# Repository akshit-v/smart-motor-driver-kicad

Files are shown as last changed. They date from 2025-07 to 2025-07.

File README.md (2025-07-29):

# Smart-Motor-Driver-kicad
A high-efficiency 60V/40A smart motor driver with real-time current and voltage sensing, reverse polarity protection, and a cost-optimized PCB design
Smart Motor Driver – Kicad

This repository contains the complete design and documentation for a smart motor driver capable of driving two high-current DC motors (up to 60V, 40A each) with real-time voltage and current sensing. The driver is built using discrete components, and gate drivers for H-bridge MOSFET control. It is designed for high-efficiency operation, integrated protection, and microcontroller-based control.

The project includes the full schematic, PCB layout, firmware interface, and performance analysis. It is intended for embedded system applications such as robotics, automation, and motorized systems requiring efficient and protected motor drive control.

---
# Project Features
- **Dual Channel Motor Drive**: Two independent H-Bridge circuits with dedicated gate drivers.
- **High Voltage and Current Support**: Operates at up to 60V input and handles continuous motor current up to 40A per channel.
- **High Efficiency**: Optimized gate drive timing, low-loss power MOSFETs, and minimized switching losses provide efficiency above 90% under load.
- **Current and Voltage Feedback**: Op-amp-based analog sensing circuits for real-time current and voltage monitoring with ±1% accuracy.
- **Reverse Polarity Protection**: Input protection circuit safeguards the board from accidental reverse connections.
- **Microcontroller Interface**: PWM-compatible logic-level inputs for speed and direction control 
- **Integrated Voltage Regulation**: Onboard buck regulators generate 5V and 3.3V rails for logic and sensors.
- **USB-to-Serial Interface**: Using a USB-to-Serial converter (CH340-C) for real-time data logging, motor control, and firmware debugging via serial terminal.
- **Modular Design**: Separated sections for control logic, power stages, sensing, and regulation.

---

## Schematic Highlights

- **Power Section**: Includes reverse polarity protection, input filtering, and buck converters (AP63205WU, AP7316-C) for 5V and 3.3V rails.
- **Gate Drivers**: MC33883 used to drive the high- and low-side N-channel MOSFETs for each H-bridge.
- **Motor Channels**: Two H-Bridge configurations, each with four MOSFETs and flyback diodes for inductive protection.
- **Current Sensing**: Differential amplifier circuits with op-amps (LM358) for low-side current sensing on each motor.
- **Voltage Monitoring**: Voltage divider and op-amp buffer stages for voltage feedback to the controller.
- **Microcontroller Interface**: PWM signal lines, direction pins, and feedback outputs prepared for logic-level interfacing.

---

## Tools and Components Used

- **Schematic & PCB Design**: KiCad
- **Analog Simulation**: Proteus
- **Gate Driver**: MC33883
- **Microcontroller Target**: ESP32
- **Op-Amps**: LM358 (for current and voltage sensing)
- **MOSFETs**: N-channel high-current rated, low Rds(on)
- **Voltage Regulators**: AP63205WU, AP7316-C for 5V and 3.3V and 74HCT244 for level shifting
- **Other Tools**: Proteus (for logic testing), T-Cad (device simulation reference)

---

## Applications

- Custom embedded robotic platforms
- Industrial or academic motor control systems

---

## Performance Summary

- **Efficiency**: >90% at full load
- **Current Measurement Error**: ±1% (tested using calibrated load)
- **MOSFET Temperature Rise**: Within safe limits under continuous 30A drive with proper heat dissipation
- **Cost**: 40% lower than comparable commercial motor drivers with similar specs

---
[View Schematic (PDF)](Schematic.pdf)
---
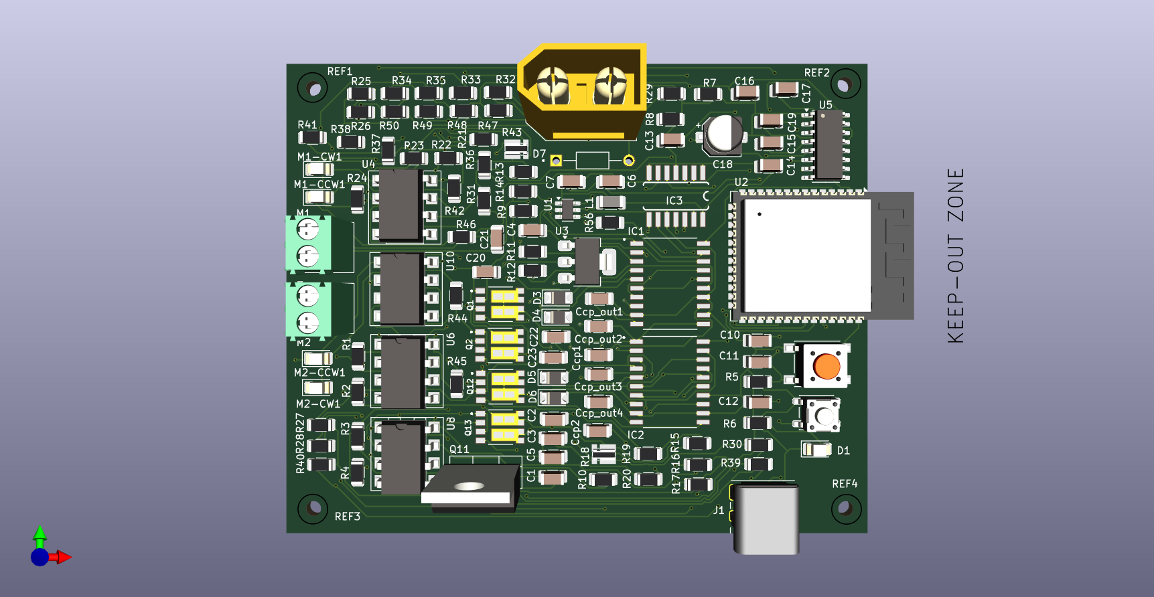
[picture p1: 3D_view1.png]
3D PCB View 1

---
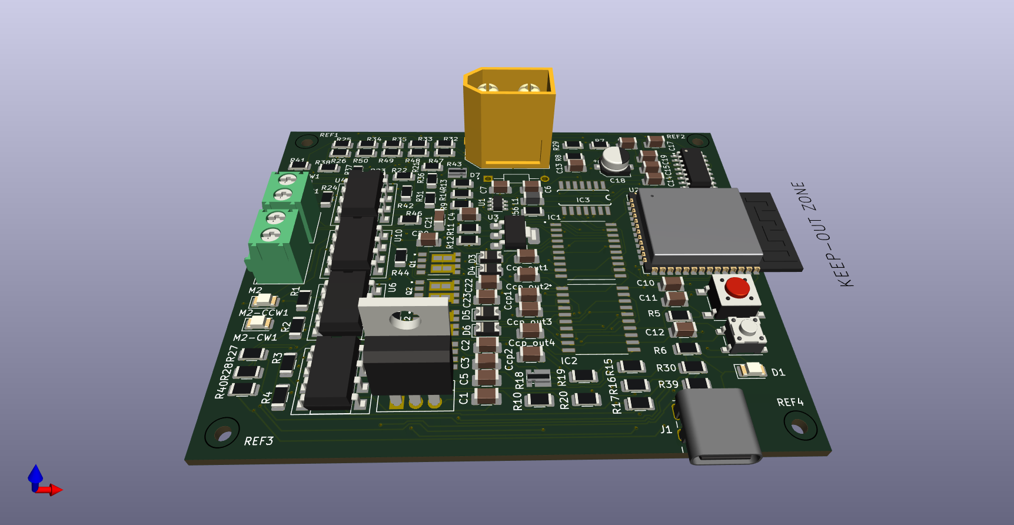
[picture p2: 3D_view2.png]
3D PCB View 2

---
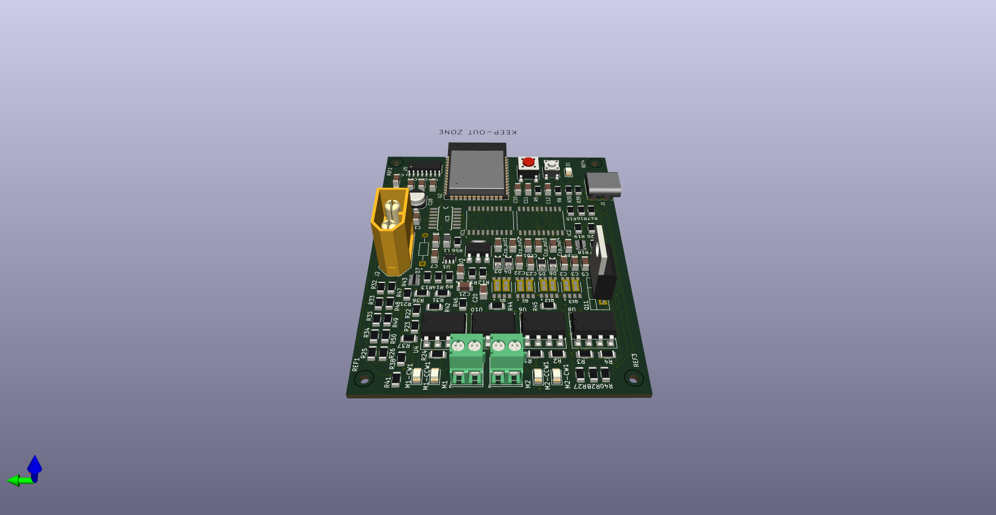
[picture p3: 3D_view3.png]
3D PCB View 3

---
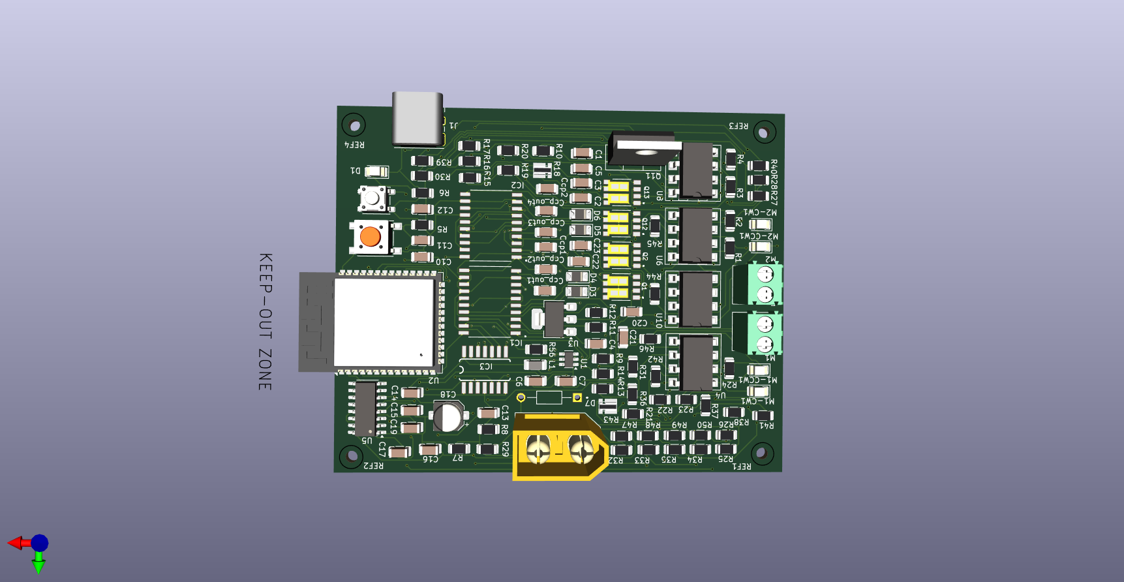
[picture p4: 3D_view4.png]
3D PCB View 4

---
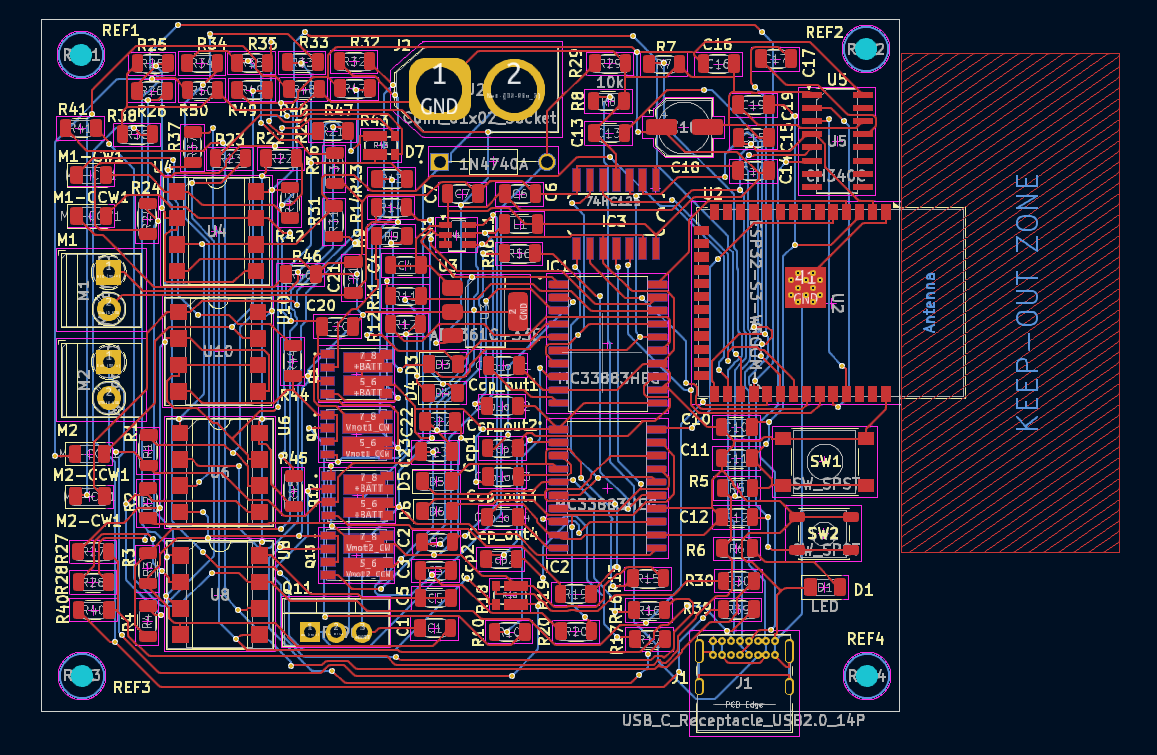
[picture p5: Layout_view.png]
Layout View

---

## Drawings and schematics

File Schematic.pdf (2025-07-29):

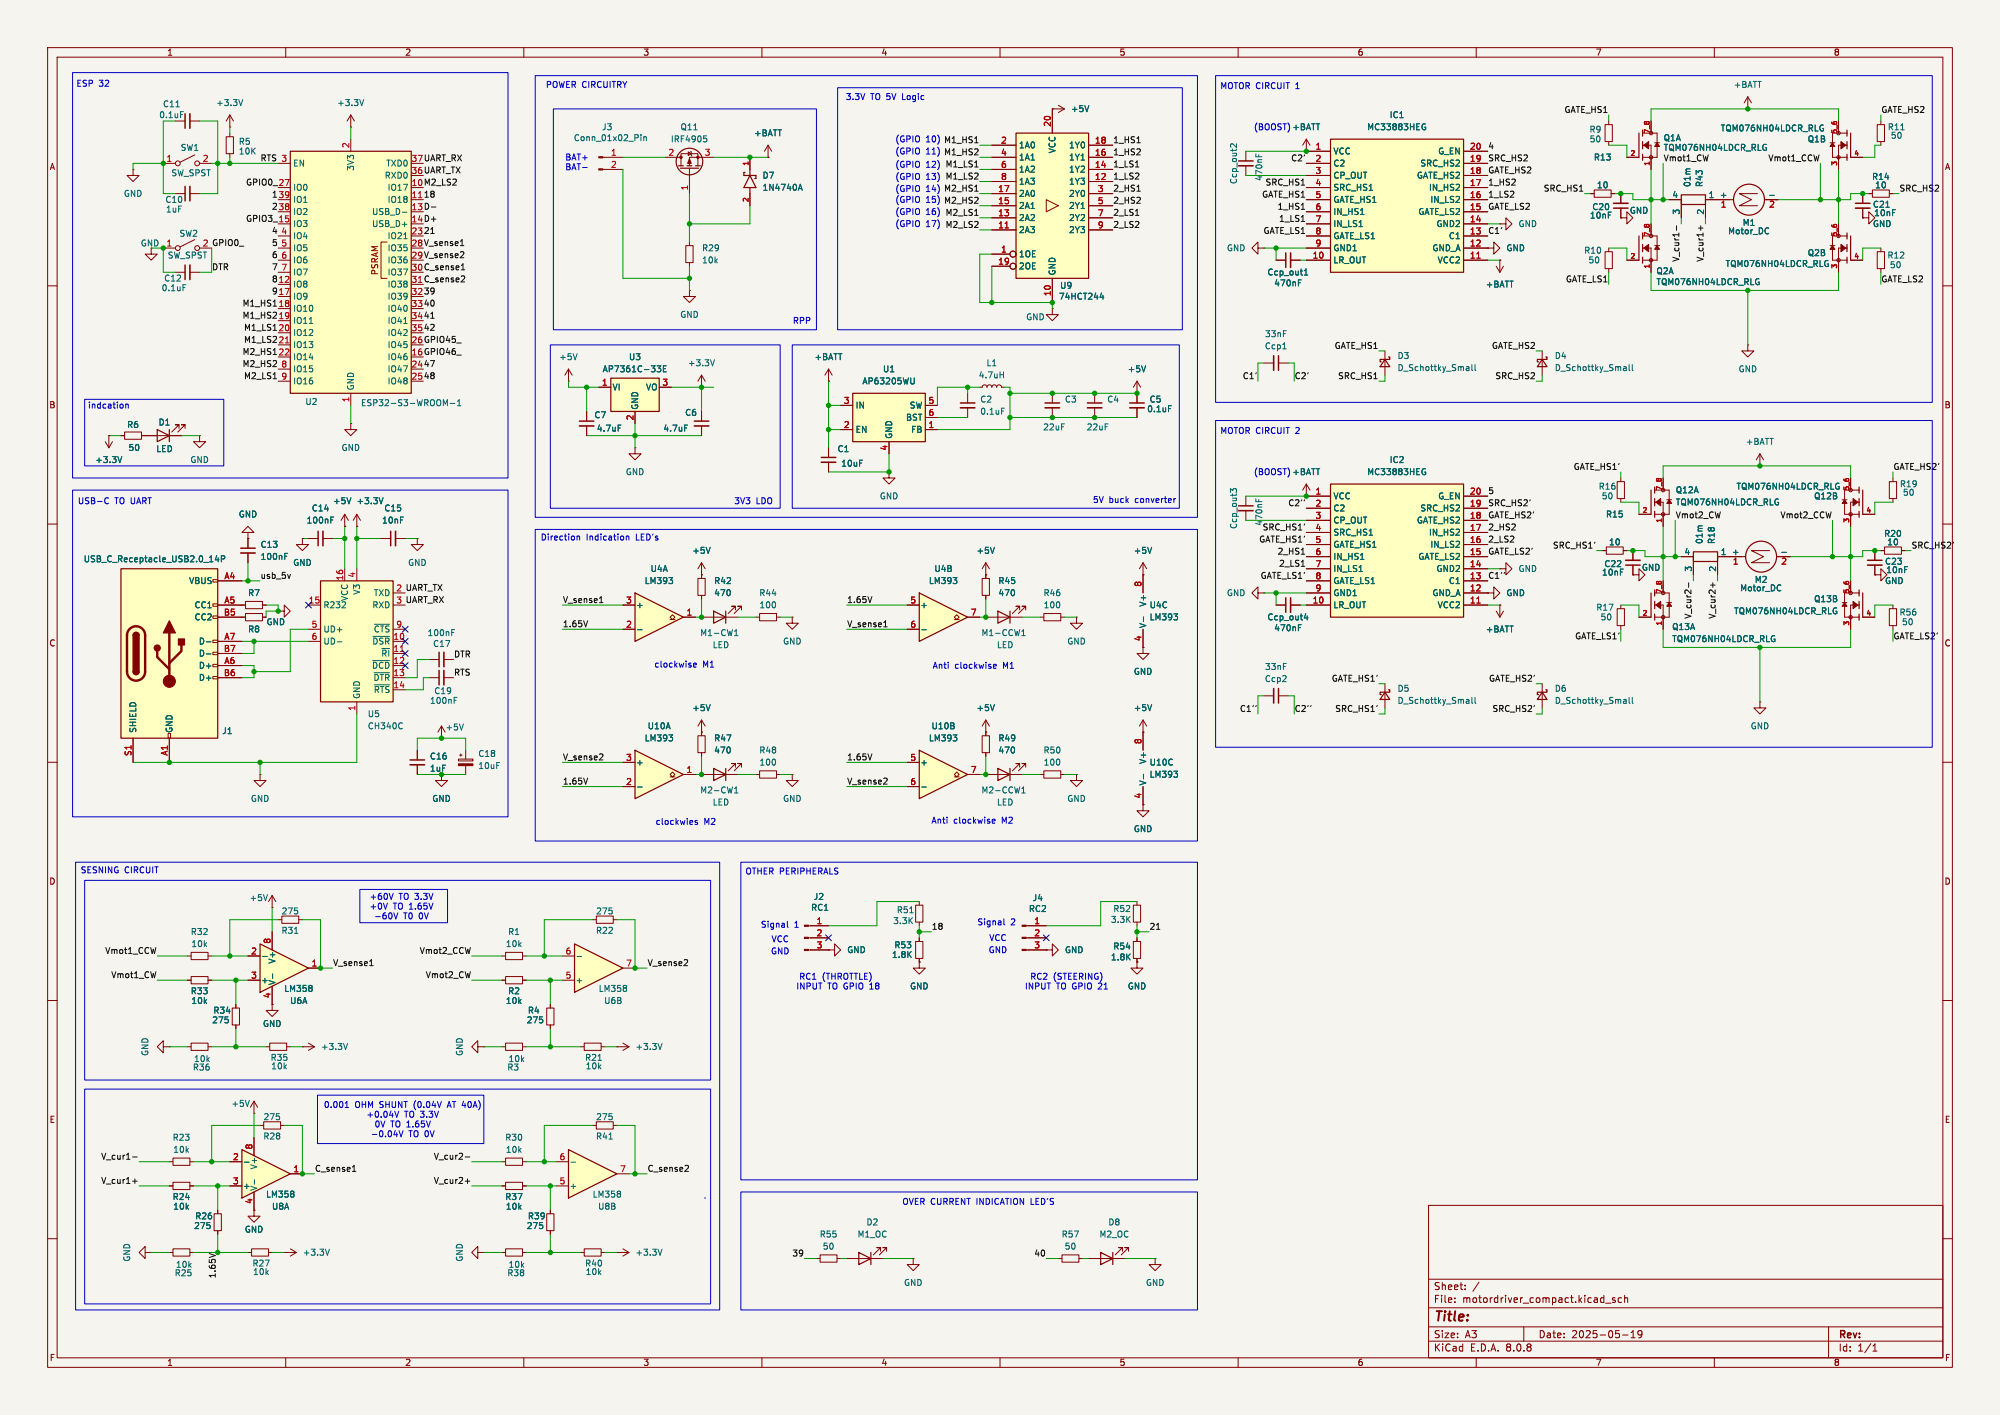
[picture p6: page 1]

1 ~{DSR} 10 ~{RI} 11 ~{DCD} 12 ~{DTR} 13 ~{RTS} 14 R232 15 VCC 16 TXD 2 RXD 3 V3

INPUT TO GPIO 21 RC1 (THROTTLE)
INPUT TO GPIO 18

0.001 OHM SHUNT (0.04V AT 40A) +0.04V TO 3.3V

Id: 1/1 Title: File: motordriver_compact.kicad_sch Sheet: /

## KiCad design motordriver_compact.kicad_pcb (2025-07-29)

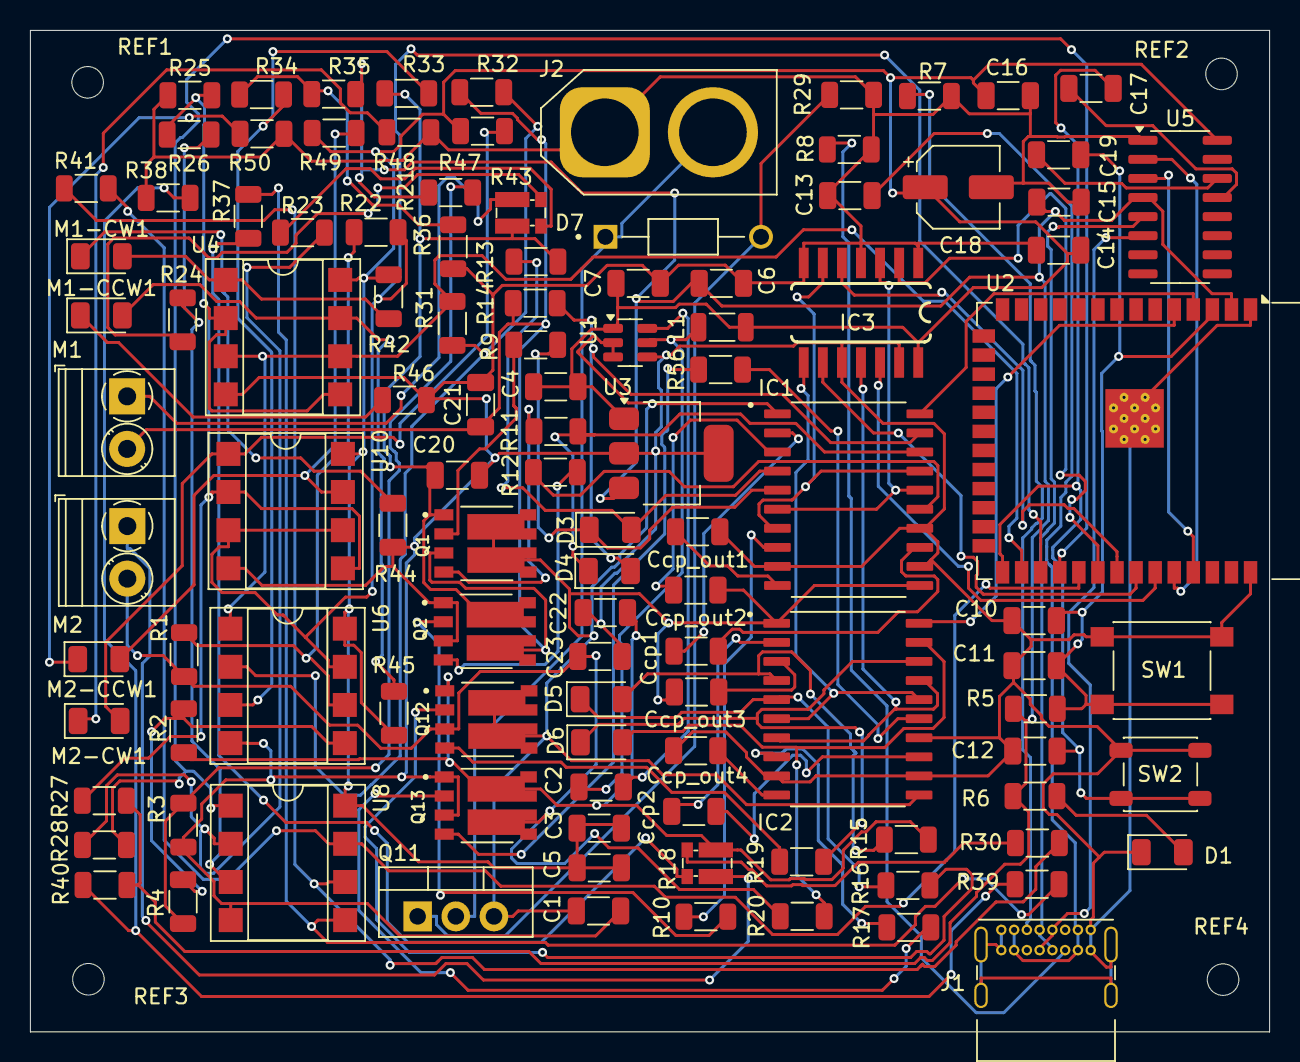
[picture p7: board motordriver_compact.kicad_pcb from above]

Board: 2 copper layers, 82.5 x 66.7 mm, 115 parts (0 on the bottom side), 92 nets.

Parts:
C1: 10uF; C_1206_3216Metric
C2, C5, C11, C12: 0.1uF; C_1206_3216Metric
C3, C4: 22uF; C_1206_3216Metric
C6, C7: 4.7uF; C_1206_3216Metric
C10, C16: 1uF; C_1206_3216Metric
C13, C14, C17, C19: 100nF; C_1206_3216Metric
C15, C20, C21, C22, C23: 10nF; C_1206_3216Metric
C18: 10uF; CP_Elec_5x3
Ccp1, Ccp2: 33nF; C_1206_3216Metric
Ccp_out1, Ccp_out2, Ccp_out3, Ccp_out4: 470nF; C_1206_3216Metric
D1: LED; LED_1206_3216Metric
D3, D4, D5, D6: D_Schottky_Small; D_1206_3216Metric
D7: 1N4740A; DIOAD1036W78L463D272
IC1, IC2: MC33883HEG; SOIC127P1030X265-20N
IC3: 74HC125; SOIC-14
J1: USB_C_Receptacle_USB2.0_14P; USB_C_Receptacle_GCT_USB4085
J2: Conn_01x02_Socket; AMASS_XT60-M_1x02_P7.20mm_Vertical
L1: 4.7uH; L_1206_3216Metric
M1, M2: Motor_DC; TerminalBlock_Phoenix_PT-1,5-2-3.5-H_1x02_P3.50mm_Horizontal
M1-CCW1, M1-CW1, M2-CCW1, M2-CW1: LED; LED_1206_3216Metric
Q1, Q2, Q12, Q13: TQM076NH04LDCR_RLG; TRANS_TQM076NH04LDCR_RLG
Q11: IRF4905; TO-220-3_Vertical
R1, R2, R3, R21, R23, R24, R25, R27, R29, R30, R32, R33, R35, R36, R37, R38, R40: 10k; R_1206_3216Metric
R4, R22, R26, R28, R31, R34, R39, R41: 275; R_1206_3216Metric
R5: 10K; R_1206_3216Metric
R6, R9, R10, R11, R12, R16, R17, R19, R56: 50; R_1206_3216Metric
R7, R8: 5k; R_1206_3216Metric
R13, R14, R15, R20: 10; R_1206_3216Metric
R18, R43: 01m; R_Shunt_Vishay_WSKW0612
R42, R45, R47, R49: 470; R_1206_3216Metric
R44, R46, R48, R50: 100; R_1206_3216Metric
REF1, REF2, REF3, REF4: MountingHole_2.1mm
SW1: SW_SPST; SW_SPST_PTS645
SW2: SW_SPST; SW_SPST_PTS647_Sx38
U1: AP63205WU; TSOT-23-6
U2: ESP32-S3-WROOM-1
U3: AP7361C-33E; SOT-223-3_TabPin2
U4, U10: LM393; DIP-8_W7.62mm_SMDSocket_SmallPads
U5: CH340C; SOIC-16_3.9x9.9mm_P1.27mm
U6, U8: LM358; DIP-8_W7.62mm_SMDSocket_SmallPads

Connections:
+3.3V: C6.1, C15.1, R5.1, R6.1, R21.2, R27.2, R35.2, R40.2, U2.2 (3V3), U3.3 (VO), U5.4 (V3)
+5V: C3.1, C3.2, C4.1, C4.2, C5.1, C5.2, C7.1, C14.2, C16.1, C18.1, IC3.14 (VCC), L1.2, R42.1, R45.1, R47.1, R49.1, U1.1 (FB), U3.1 (VI), U4.8 (V+), U5.16 (VCC), U6.8 (V+), U8.8 (V+), U10.8 (V+)
+BATT: C1.1, Ccp_out2.1, Ccp_out3.1, IC1.1 (VCC), IC1.11 (VCC2), IC2.1 (VCC), IC2.11 (VCC2), Q1.5_6, Q1.7_8, Q11.3 (S), Q12.5_6, Q12.7_8, U1.2 (EN), U1.3 (IN)
/1.65V: R25.2, R26.1, R27.1, U4.2 (-), U4.5 (+), U10.2 (-), U10.5 (+)
/4: IC1.20 (G_EN), U2.4 (IO4)
/5: IC2.20 (G_EN), U2.5 (IO5)
/C1': Ccp1.2, IC1.13 (C1)
/C1'': Ccp2.2, IC2.13 (C1)
/C2': Ccp1.1, IC1.2 (C2)
/C2'': Ccp2.1, IC2.2 (C2)
/C_sense1: R28.2, U2.30 (IO37), U8.1
/C_sense2: R41.2, U2.31 (IO38), U8.7
/DTR: C12.2, C17.2, SW2.2 (B), U2.27 (IO0)
/GATE_HS1: D3.1 (K), IC1.5 (GATE_HS1), R9.1
/GATE_HS1': D5.1 (K), IC2.5 (GATE_HS1), R16.1
/GATE_HS2: D4.1 (K), IC1.18 (GATE_HS2), R11.2
/GATE_HS2': D6.1 (K), IC2.18 (GATE_HS2), R19.2
/GATE_LS1: IC1.8 (GATE_LS1), R10.1
/GATE_LS1': IC2.8 (GATE_LS1), R17.1
/GATE_LS2: IC1.15 (GATE_LS2), R12.1
/GATE_LS2': IC2.15 (GATE_LS2), R56.1
/M39: IC3.2 (1A), U2.32 (IO39)
/M39_5V: IC1.6 (IN_HS1), IC1.16 (IN_LS2), IC3.3 (1Y)
/M40: IC3.5 (2A), U2.33 (IO40)
/M40_5V: IC1.7 (IN_LS1), IC1.17 (IN_HS2), IC3.6 (2Y)
/M41: IC3.9 (3A), U2.34 (IO41)
/M41_5V: IC2.6 (IN_HS1), IC2.16 (IN_LS2), IC3.8 (3Y)
/M42: IC3.12 (4A), U2.35 (IO42)
/M42_5V: IC2.7 (IN_LS1), IC2.17 (IN_HS2), IC3.11 (4Y)
/RTS: C10.2, C11.2, C19.2, R5.2, SW1.2 (B), U2.3 (EN)
/SRC_HS1: D3.2 (A), IC1.4 (SRC_HS1), R13.1
/SRC_HS1': D5.2 (A), IC2.4 (SRC_HS1), R15.1
/SRC_HS2: D4.2 (A), IC1.19 (SRC_HS2), R14.2
/SRC_HS2': D6.2 (A), IC2.19 (SRC_HS2), R20.2
/UART_RX: U2.37 (TXD0), U5.3 (RXD)
/UART_TX: U2.36 (RXD0), U5.2 (TXD)
/V_cur1+: R24.1, R43.2
/V_cur1-: R23.1, R43.3
/V_cur2+: R18.2, R37.1
/V_cur2-: R18.3, R30.1
/V_sense1: R31.2, U2.28 (IO35), U4.3 (+), U4.6 (-), U6.1
/V_sense2: R22.2, U2.29 (IO36), U6.7, U10.3 (+), U10.6 (-)
/Vmot1_CCW: C21.1, M1.2 (-), Q1.3, Q2.5_6, R14.1, R32.1
/Vmot1_CW: C20.2, Q1.1, Q2.7_8, R13.2, R33.1, R43.4
/Vmot2_CCW: C23.1, M2.2 (-), Q12.3, Q13.5_6, R1.1, R20.1
/Vmot2_CW: C22.2, Q12.1, Q13.7_8, R2.1, R15.2, R18.4
/usb_5v: C13.2, J1.A4 (VBUS), J1.A9 (VBUS), J1.B4 (VBUS), J1.B9 (VBUS)
GND: C1.2, C6.2, C7.2, C10.1, C11.1, C12.1, C13.1, C14.1, C15.2, C16.2, C18.2, C20.1, C21.2, C22.1, C23.2, Ccp_out1.1, Ccp_out4.1, D1.1 (K), IC1.9 (GND1), IC1.12 (GND_A), IC1.14 (GND2), IC2.9 (GND1), IC2.12 (GND_A), IC2.14 (GND2), IC3.1 (1OE), IC3.4 (2OE), IC3.7 (GND), IC3.10 (3OE), IC3.13 (4OE), J1.A1 (GND), J1.A12 (GND), J1.B1 (GND), J1.B12 (GND), J1.S1 (SHIELD), J2.1, Q2.1, Q2.3, Q13.1, Q13.3, R3.1, R7.2, R8.2, R25.1, R29.2, R36.1, R38.1, R44.2, R46.2, R48.2, R50.2, SW1.1 (A), SW2.1 (A), U1.4 (GND), U2.1 (GND), U2.40 (GND), U2.41 (GND), U3.2 (GND), U4.4 (V-), U5.1 (GND), U6.4 (V-), U8.4 (V-), U10.4 (V-)
unnamed: D1.2 (A), R6.2
unnamed: Ccp_out2.2, IC1.3 (CP_OUT)
unnamed: Ccp_out1.2, IC1.10 (LR_OUT)
unnamed: Ccp_out3.2, IC2.3 (CP_OUT)
unnamed: Ccp_out4.2, IC2.10 (LR_OUT)
unnamed: J1.A5 (CC1), R7.1
unnamed: J1.B5 (CC2), R8.1
unnamed: D7.1, J2.2, Q11.2 (D)
unnamed: M1.1 (+), R43.1
unnamed: M1-CCW1.2 (A), R45.2, U4.7
unnamed: M1-CCW1.1 (K), R46.1
unnamed: M1-CW1.2 (A), R42.2, U4.1
unnamed: M1-CW1.1 (K), R44.1
unnamed: M2.1 (+), R18.1
unnamed: M2-CCW1.2 (A), R49.2, U10.7
unnamed: M2-CCW1.1 (K), R50.1
unnamed: M2-CW1.2 (A), R47.2, U10.1
unnamed: M2-CW1.1 (K), R48.1
unnamed: Q1.2, R9.2
unnamed: Q1.4, R11.1
unnamed: Q2.2, R10.2
unnamed: Q2.4, R12.2
unnamed: D7.2, Q11.1 (G), R29.1
unnamed: Q12.2, R16.2
unnamed: Q12.4, R19.1
unnamed: Q13.2, R17.2
unnamed: Q13.4, R56.2
unnamed: R3.2, R4.1, R21.1
unnamed: R34.1, R35.1, R36.2
unnamed: R38.2, R39.1, R40.1
unnamed: C2.2, U1.6 (BST)
unnamed: C2.1, L1.1, U1.5 (SW)
unnamed: J1.A6 (D+), J1.B6 (D+), U5.5 (UD+)
unnamed: J1.A7 (D-), J1.B7 (D-), U5.6 (UD-)
unnamed: C17.1, U5.13 (~DTR)
unnamed: C19.1, U5.14 (~RTS)
unnamed: R33.2, R34.2, U6.3 (+)
unnamed: R31.1, R32.2, U6.2 (-)
unnamed: R2.2, R4.2, U6.5 (+)
unnamed: R1.2, R22.1, U6.6 (-)
unnamed: R24.2, R26.2, U8.3 (+)
unnamed: R23.2, R28.1, U8.2 (-)
unnamed: R37.2, R39.2, U8.5 (+)
unnamed: R30.2, R41.1, U8.6 (-)
